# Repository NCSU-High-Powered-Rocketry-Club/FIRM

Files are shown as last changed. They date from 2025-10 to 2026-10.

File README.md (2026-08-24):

# FIRM
Filtered Inertial Rotation Module

FIRM is a project by the NCSU High Powered Rocketry Club to develop a flight computer for high powered rockets. The flight computer is designed to provide accurate attitude and position data during flight using an array of sensors and advanced filtering algorithms.

It is also designed to be modular and easily adaptable to different rocket configurations and mission requirements. The project will also have a custom PCB design to integrate all the components into a compact and lightweight package suitable for high-speed flight.

This repository contains both the embedded code (written in C) that is compiled directly on the STM32 microcontroller, as well as the client code (written in Rust) that will act as the interface between the user-facing API and the hardware.

## Hardware Components

The components used in this project include:

| Part Number | Description | Datasheet Link |
| --- | --- | --- |
| ICM-45686 | 6 Axis IMU | [Datasheet](https://www.mouser.com/catalog/specsheets/TDK_DS_000577_ICM_45686.pdf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) |
| STM32F405RGT6  | Microcontroller | [Datasheet](https://www.st.com/resource/en/datasheet/dm00037051.pdf) |
| MMC5983MA | Magnetometer | [Datasheet](https://media.digikey.com/pdf/Data%20Sheets/MEMSIC%20PDFs/MMC5983MA_RevA_4-3-19.pdf)  |
| BMP581 | Pressure Sensor | [Datasheet](https://www.bosch-sensortec.com/media/boschsensortec/downloads/datasheets/bst-bmp581-ds004.pdf) |

## Project Setup

To set up the project for either embedded development in C or client development in Rust, you will need [uv](https://docs.astral.sh/uv/) installed, and clone the repository:
```bash
git clone https://github.com/NCSU-High-Powered-Rocketry-Club/FIRM.git
```

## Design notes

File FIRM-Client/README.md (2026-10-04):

# FIRM-Client

A modular Rust library for parsing FIRM data packets, with bindings for Python and WebAssembly.

## Project Structure

The project is organized as a Cargo workspace with the following crates:

- **`firm_core`**: The core `no_std` crate containing the raw USB message parser and data structures. This is the foundation for all other crates and can be used in embedded environments.
- **`firm_rust`**: A high-level Rust API that uses `serialport` to read from a serial device and provides a threaded client for receiving packets.
- **`firm_python`**: Python bindings for the Rust client.
- **`firm_typescript`**: WebAssembly bindings and TypeScript code for using the parser in web applications.

## Philosophy

The goal of FIRM-Client is to provide a single, efficient, and correct implementation of the FIRM parser that can be used across different ecosystems (Rust, Python, Web/JS, Embedded).
By centralizing the parsing logic in `firm_core`, we ensure consistency and reduce code duplication.

## Building

### Prerequisites

- Rust (latest stable)
- Python 3.10+ (for Python bindings)
- `maturin` (for building Python wheels)
- `wasm-pack` (for building WASM)
- Node.js/npm (for TypeScript)

### Build Instructions

We assume that you are using a Unix-like environment (Linux or macOS).

Windows users may need to adapt some commands (we will mention where this is the case), or use
WSL (Windows Subsystem for Linux) for best compatibility.

Make sure you have [Cargo](https://rustup.rs) and [uv](https://docs.astral.sh/uv/getting-started/installation/) installed.

You would also need npm if you want to test the web/TypeScript bindings.
Install it and Node.js here: https://nodejs.org/en/download/

1.  **Build all Rust crates:**

    ```bash
    cargo build
    ```

2.  **Build Python bindings:**

    ```bash
    cargo build -p firm_python
    uv sync
    # or to build a wheel
    uv run maturin build --release
    ```

3.  **Build WASM/TypeScript:**

    ```bash
    cargo install wasm-pack
    cd firm_typescript
    npm install
    npm run clean
    npm run build

    # For testing the code with examples/index.html
    npx serve .
    ```

## Running Tests

Ensure that you are in the FIRM-Client folder and run:

```bash
cargo test
```

## Usage

### Rust

Add `firm_rust` to your `Cargo.toml`.

```rust
use firm_rust::FirmClient;
use std::{thread, time::Duration};

fn main() {
    let mut client = FIRMClient::new("/dev/ttyUSB0", 2_000_000, 0.1);
    client.start();

    loop {
        while let Ok(packet) = client.get_packets(Some(Duration::from_millis(100))) {
            println!("{:#?}", packet);
        }
    }
}
```

### Python

You can install the library via pip (once published) or build from source.

```bash
pip install firm-client
```

This library supports Python 3.10 and above, including Python 3.14 free threaded.

```python
from firm_client import FIRMClient
import time

# Using context manager (automatically starts and stops)
with FIRMClient("/dev/ttyUSB0", baud_rate=2_000_000, timeout=0.1) as client:
    client.get_data_packets(block=True)  # Clear initial packets
    client.zero_out_pressure_altitude()
    while True:
        packets = client.get_data_packets()
        for packet in packets:
            print(packet.timestamp_seconds, packet.raw_acceleration_x_gs)
```

### Web (TypeScript)

todo: Add usage example.

### IMU Fixture Calibration

The interactive accelerometer and gyroscope-bias calibration utility uses the Python client and
NumPy. From the `FIRM-Client` directory, run:

```bash
uv run --extra extras python scripts/calibrate_imu.py COM12
```

Replace `COM12` with the device's serial port. The utility checks for identity IMU calibration,
guides the operator through all 26 numbered fixture sides, prints the fitted values, and asks before
writing them to the device. It does not save captured samples or calibration results to disk.

## Publishing

This is mostly for maintainers, but here are the steps to publish each crate to their respective package registries:

### Rust API (crates.io)

todo (idk actually know yet)

### Python Bindings (PyPI)

We need to to first build wheels for each platform, right now the workflow is to do this locally
and then upload to PyPI. At the minimum, we build for Linux x86_64 and aarch64 for python versions
3.10+, including free threaded wheels.

1. Always bump the version in `firm_python/Cargo.toml` before publishing.

2. Build the wheels 
```bash
# If you're on Linux
./compile.sh

# If you're on Windows
.\compile.ps1
```

This will create wheels in the `target/wheels` directory, for Python versions 3.10 to 3.14,
for both x86_64 and aarch64.

3. Make sure you also have a source distribution:

```bash
uv run maturin sdist
```

4. We will use `uv` to publish these wheels to PyPI. Make sure you are part of the HPRC
   organization on PyPI, so you have access to the project and can publish new versions.

```bash
uv publish target/wheels/*
```

This will ask for PyPI credentials, make sure you get the token from the website.

### TypeScript Package (npm)

1. Always bump the version in `firm_typescript/Cargo.toml` and `package.json` before publishing. Make sure they match.

2. Login to npm

`npm login`

3. Publish it

`npm publish`

(Ensure the version in `package.json` is bumped before publishing.)

## License

Licensed under the MIT License. See `LICENSE` file for details.

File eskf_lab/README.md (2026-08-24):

# FIRM ESKF desktop lab

This tool compiles the production STM32 error-state Kalman filter sources as a fast native
desktop executable, aligns manager-built sensor Parquet, replays it through the filter, and writes
compressed Parquet results for analysis and plotting. It does not reimplement the filter math in
Python.

## Quick start

From the repository root:

```powershell
uv sync
uv run firm-log ingest --launch my-launch --recording primary --flight LOG1.FRM --mag-cal LOG2.FRM --hardware new
uv run firm-log build my-launch/primary
uv run firm-eskf list
uv run firm-eskf run my-launch/primary
uv run firm-eskf serve
```

With no dataset names, `prepare` and `run` process every current recording in `flight_data`:

```powershell
uv run firm-eskf run
```

The first run aligns the native-rate Parquet files. Later runs reuse the aligned Parquet and
binary input, so changing ESKF C code normally requires only an incremental native compile and
replay.

For the normal multi-launch workflow, run every dataset once and then use one tabbed dashboard:

```powershell
uv run firm-eskf run
uv run firm-eskf serve
```

## Managed recording format

ESKF discovers only current recordings under the repository's `flight_data` manager. It does not
scan or fall back to `eskf_lab/datasets`; those legacy files are intentionally left in place while
the new archive starts empty. Until a recording has been ingested and built, `list` is empty and
`prepare`, `run`, and no-argument `serve` report that managed data is unavailable.

```text
flight_data/launches/my-launch/recordings/primary/
  recording.yaml
  originals/flight.frm
  originals/magnetometer-calibration.frm
  derived/flight/current.frm
  decoded/barometer.parquet
  decoded/imu.parquet
  decoded/magnetometer.parquet
  decoded/high-g.parquet
```

The manager writes stable corrected column names and keeps raw and uncalibrated fields alongside
them. ESKF retains those extra fields with a sensor prefix so they remain selectable in plots.
Manager outputs are always expressed in the new-hardware sensor frame, including migrated legacy
recordings, so ESKF replay consistently uses the current hardware orientation matrices.

When `rocket_properties.json` is present, it must contain:

```json
{
  "rocket": {
    "rocket_Cd": 0.393,
    "rocket_dry_mass_kg": 16.601,
    "rocket_cross_sectional_area_m2": 0.0182414692475
  }
}
```

The lab then runs HPRM's one-dimensional RK45 apogee predictor from the ESKF altitude and vertical
velocity during the coast-to-apogee portion of the replay. The resulting
`hprm_predicted_apogee_m` column is included in the default dashboard and report plots. Datasets
without the optional file have no HPRM column or graph.

## Commands

```text
firm-eskf list
firm-eskf prepare [DATASET ...] [--force]
firm-eskf run [DATASET ...] [--force-prepare] [--force]
firm-eskf test
firm-eskf inspect RESULT
firm-eskf plot RESULT [--columns COLUMN ...] [--open]
firm-eskf compare RESULT RESULT [--columns COLUMN ...] [--open]
firm-eskf serve [RESULT] [--port 8050]
```

`RESULT` can be a `result.parquet` path, a run directory, or a dataset name. A dataset name selects
its latest run. `inspect` lists every available raw and filter column.

`run --force` bypasses the native ESKF tests and replays the filter even if those tests would fail.
It is intended for deliberately testing broken or experimental filter changes. The older,
equivalent spelling `--skip-native-tests` remains supported. This does not rebuild input caches;
use `--force-prepare` separately when that is required.

`serve` starts a dashboard whose column selector lazily reads only the requested Parquet fields.
With no `RESULT`, it opens every dataset's latest run in a single browser dashboard. Each dataset
has a top-level tab; tabs have a minimum width and wrap to additional rows on smaller screens. Pass
`RESULT` to serve only one dataset instead:

```powershell
uv run firm-eskf serve
uv run firm-eskf serve my-launch
```

`plot` writes a standalone HTML report for one run, while `compare` overlays the same selected
columns across two or more runs. Both use min/max downsampling so short spikes survive while the
browser receives a manageable number of points. When both are selected,
`raw_baro_altitude_m` and `eskf_position_z_m` are intentionally drawn together on the same
**Altitude (m)** chart for direct comparison.

## Replay model

The filter uses IMU, barometer, and magnetometer data. High-g accelerometer values are aligned and
retained for comparisons but are not passed to the current ESKF because
`STM32/Core/Src/tasks/filter_data_task.c` does not use that sensor.

The manager resolves the recording's effective accelerometer, gyroscope, magnetometer, and high-g
calibration before writing Parquet. ESKF consumes those corrected columns directly while retaining
the raw and uncalibrated columns for inspection.

Sensor files have independent timestamps. The magnetometer is the slowest required stream in FIRM
logs, so its samples form the update clock. Each replay row uses the most recent IMU, barometer,
and high-g sample at or before that timestamp, reproducing the firmware's shared-data snapshot
semantics. The first two seconds are accumulated for ESKF initialization.

The native target directly compiles:

- `error_state_kalman_filter.c`
- `eskf_functions.c`
- `eskf_config.c`
- `matrix_helper.c`

A small host shim supplies firmware settings without HAL or FreeRTOS. Results record the filter
source hash, Git revision and dirty state, dataset fingerprint, build path, timing, and descriptive
metrics. Pressure-derived altitude is useful for comparing smoothness but is explicitly not treated
as ground truth.

## Reading results and warnings

Each replay creates a timestamped directory under `eskf_lab/results/<dataset>/` containing:

- `result.parquet`: the aligned raw sensor fields, ESKF state, covariance diagonals, and diagnostics
- `metrics.json`: speed, apogee, smoothness, and finite-state summary
- `run.json`: source/configuration provenance for reproducing the run

`non-finite state values` means at least one ESKF state became `NaN` or `+/-Infinity`. This is a
filter numerical-stability warning, not a CSV parsing warning. Once it happens, later calculations
usually remain invalid. Use the last finite time region in the dashboard, covariance columns, and
the raw sensor traces to diagnose the configuration or model behavior that preceded it.

## Generated files

Generated ESKF artifacts are ignored by Git:

- `eskf_lab/cache`: aligned Parquet and compact replay input
- `eskf_lab/results`: timestamped result Parquet, metadata, metrics, and plots
- `eskf_lab/build`: native CMake build

Delete a recording's cache or use `prepare --force` to rebuild it. The manager build fingerprint
automatically invalidates stale data caches; CMake automatically rebuilds changed filter sources.

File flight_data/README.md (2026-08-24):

# FIRM flight data

This directory is the catalog root for the FIRM flight-data manager.

Each launch can contain several recordings (for example, airbrakes, grave, and zombie). A recording
contains an immutable flight log, an optional immutable magnetometer-calibration log, a manifest,
and rebuildable derived artifacts.

```text
flight_data/launches/<launch>/recordings/<recording>/
  recording.yaml
  originals/flight.frm
  originals/magnetometer-calibration.frm
  overrides/calibration.yaml
  derived/flight/current.frm
  derived/magnetometer-calibration/current.frm
  derived/effective-calibration.yaml
  derived/build.json
  decoded/barometer.parquet
  decoded/imu.parquet
  decoded/magnetometer.parquet
  decoded/high-g.parquet
  decoded/magnetometer-calibration.parquet
```

Start by ingesting a pair of logs, then build their current artifacts:

```powershell
uv run firm-log ingest --launch jackpot-4 --recording airbrakes `
  --flight C:\logs\LOG42.FRM --mag-cal C:\logs\LOG40.FRM --hardware new
uv run firm-log build jackpot-4/airbrakes
uv run firm-eskf list
```

Originals are copied and SHA-256 hashed. Manager commands never modify them. Calibration overrides,
trim windows, migrated logs, and decoded data are all reproducible from `recording.yaml`.

Every recording declares `--hardware old|new` at ingestion. Migration rotates old-hardware IMU
accelerometer and gyroscope bins into the new-hardware sensor frame and transforms their calibration
offsets and matrices with the same change of basis. Barometer and magnetometer data are unchanged;
old recordings may legitimately produce an empty high-g Parquet file. For recordings ingested
before this field existed, use `firm-log hardware set LAUNCH/RECORDING old|new` before building.
Calibration overrides are written in the recording's original sensor frame; the build transforms
old-hardware accel and gyro overrides along with the calibration stored in the original header.

Use `firm-log inspect`, `validate`, and `status` to audit recordings. Calibration changes use
`firm-log calibration set`; explicit or reviewed phase trim windows use `firm-log trim`; `rebuild
--all` refreshes every stale recording. CSV remains an explicit export format rather than an
authoritative artifact.

Git tracks catalog manifests and documentation, but ignores acquired logs, derived logs, Parquet,
and local indexes. A team storage or synchronization system can therefore mirror the complete
`flight_data` tree without putting large binaries in normal Git history; `archive.yaml`,
`launch.yaml`, and `recording.yaml` remain the authoritative, rebuildable catalog.

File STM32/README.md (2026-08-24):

# Embedded FIRM
This contains all of the STM32-based embedded code that runs on FIRM itself.

## Environment Setup

1. Download the STM32CubeCLT from the [STMicroelectronics website](https://www.st.com/en/development-tools/stm32cubeclt.html) and install it on your machine.

2. Install the [STM32 VS Code Extension](https://marketplace.visualstudio.com/items?itemName=stmicroelectronics.stm32-vscode-extension).

3. Restart VS Code.

4. Open the STM32 folder of the repo in VS Code and use the extension to import the folder with the
"Import CMake project" button.

5. Configure your workspace by accepting the default settings from the pop-up messages in VS Code.

6. Click the "Build" button on the bottom status bar to build the project.

7. Run `uv sync`.

8. Run `uv run pre-commit install` to set up the git hook for automatic code formatting and linting, using `clang-format` & `clang-tidy`.

## Building the project

In VS Code, press `Ctrl+Shift+B` to bring up the build menu.
Then click "CMake: build". You should see the build output in the terminal.

## Flashing the firmware

To flash the firmware onto the STM32 microcontroller, follow these steps:

1. Connect the ST-Link Debugger to your computer, and jump the GND, SWDIO, and SWCLK pins from the ST-Link onto FIRM (see the back of the PCB for pin locations).

2. Power FIRM via a USB-C cable or another power source.

3. In VSCode, hit `Ctrl+Shift+P` to open the command palette. Then search for `Run Task` and select it. Then select the option which says to flash via SWD. 

### Running the debugger

Running the debugger is very similar to flashing the firmware.

Make sure you still have the ST-Link hooked onto FIRM, and then go to the Run and Debug tab on the left side of VS Code (or hit `Ctrl+Shift+D`).

Then simply click the green play button at the top of the sidebar to start a debugging session.

## Tracing

Tracing can be used to show how long each thread is running for.

To get a trace, debug the board with a ST-LINK. Pause execution, open up the `Debug Console`, and run

```
>dump binary value trace.bin trace_data
```

The `>` is required for the command to be interpreted as a GDB command. This will save the trace to `STM32/trace.bin`.

To format the trace, run `uv run .\python\scripts\convert_trace.py -i .\STM32\trace.bin -o trace.json` from the root of the repository.

This will produce a json trace that can be visualized in [spall](https://gravitymoth.com/spall/spall.html) or [perfetto](https://ui.perfetto.dev)

## Third party licenses

Contains FATFS changes from https://github.com/MathewMorrow/STM32-SD-Logging-DMA (MIT Licensed)

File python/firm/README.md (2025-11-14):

## FIRM Python Library

This directory contains the Python library for FIRM, which provides tools and utilities for working with the FIRM firmware and hardware components.

## Installation

You can install the FIRM Python library using pip:

```bash
pip install firm-hprc
```

## Usage

After installing the library, you can import it in your Python scripts:

```python
from firm import FIRM

firm = FIRM("/path/to/device")  # e.g. "/dev/ttyUSB0" or "COM3"
firm.initialize()
data = f.get_data_packets()
print(data[0].accel_x_meters_per_s2)
```

The returned data packet is a `FIRMPacket`, which contains various sensor readings and status information. See the source code [here](https://github.com/NCSU-High-Powered-Rocketry-Club/FIRM/blob/main/python/firm/packets.py) on what fields are available.

## Zeroing Out Pressure Altitude

You can zero out the pressure altitude reading to set the current altitude as the new reference (0 meters) using the `zero_out_pressure_altitude` method:

```python
firm.zero_out_pressure_altitude()
packets = firm.get_data_packets()
print(packets[0].pressure_altitude_meters)  # Should be ~0.0 after zeroing out
```

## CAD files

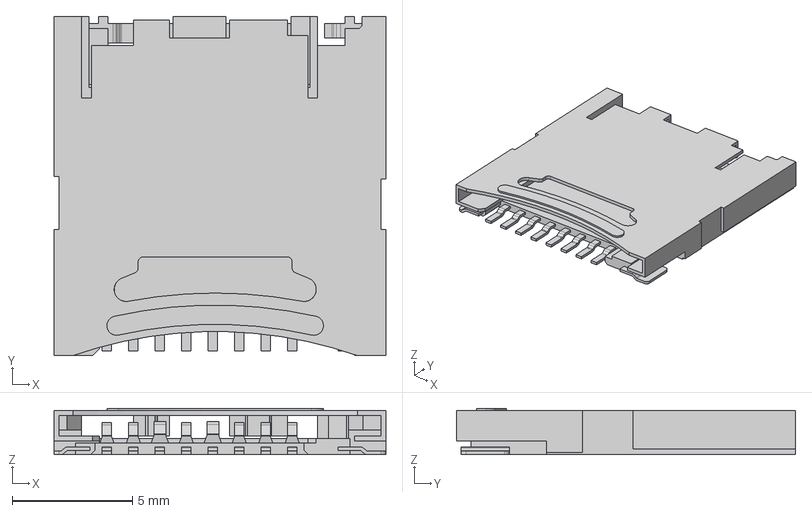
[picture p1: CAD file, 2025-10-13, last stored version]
KiCad/3dmodels/DM3CS-SF.step
13.8 x 14.1 x 1.93 mm

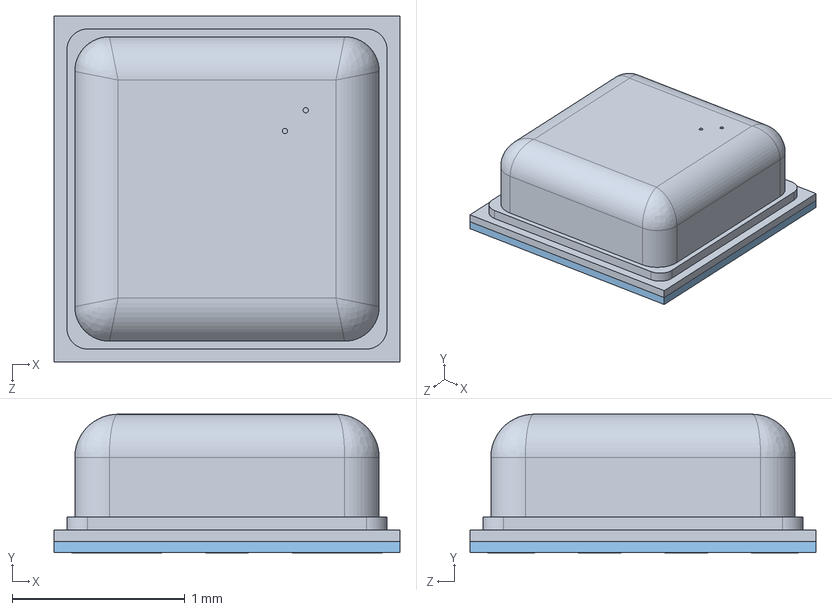
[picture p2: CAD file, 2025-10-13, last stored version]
KiCad/3dmodels/BMP581.step
2.00 x 0.801 x 2.00 mm

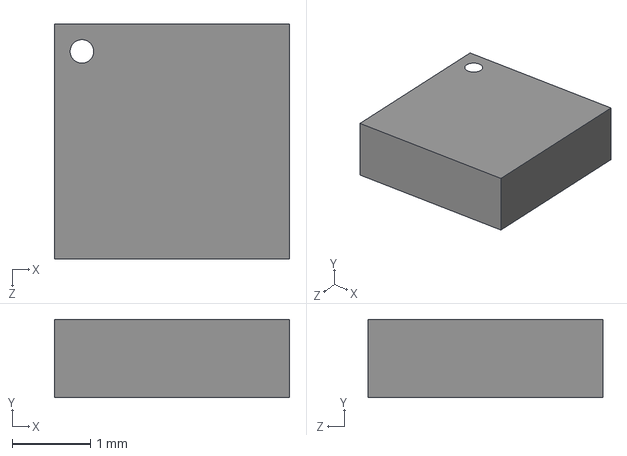
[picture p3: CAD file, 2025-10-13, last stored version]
KiCad/3dmodels/MMC5983MA.step
3.00 x 1.00 x 3.00 mm

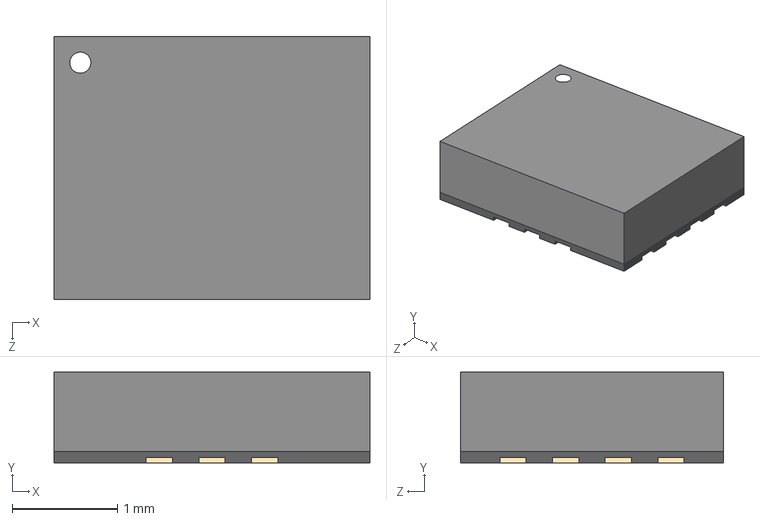
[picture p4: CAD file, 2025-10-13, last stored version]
KiCad/3dmodels/ICM-45686.step
3.00 x 0.86 x 2.50 mm

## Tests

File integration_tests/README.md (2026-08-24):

# Integration Tests

This folder contains pytest-based integration tests for the TypeScript -> FIRM Client -> mocked USB -> STM32 command pipeline.

The first test exercises `getDeviceInfo()` end to end:

1. TypeScript sends the command.
2. The FIRM Client writes the one-byte command ID over a mocked serial link.
3. A Python USB bridge forwards the command into a small host-built STM32 harness.
4. The STM32 `dispatch_command()` path builds the response.
5. The raw ID-plus-payload response returns to the TypeScript client and is asserted in pytest.

Run from the repo root with:

```bash
pytest integration_tests
```

Requirements:

- Python 3.10+
- `pytest`
- Node.js
- A C compiler such as `gcc` or `clang`

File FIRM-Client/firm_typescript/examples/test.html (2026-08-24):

# FIRM Client Test

Connect to Device

Waiting for connection...

Set Name

Get Device Config Get Device Info Get Calibration

Run Mag Calibration Cancel Reboot

Set Mag Calibration

Set IMU Calibration

Stream Mock Log

Config output...

### Latest Packet:

{ No packet data yet }

### Incoming Serial Bytes:

{ No raw bytes yet }

### Outgoing Serial Bytes:

{ No outgoing bytes yet }

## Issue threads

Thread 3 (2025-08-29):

Code formatting

harshil21, 2025-08-29:
It is very essential to format the code, STM32CubeIDE's builtin formatting tool is complete crap. I don't know the C ecosystem very well, but it seems that [`clang-format`](https://clang.llvm.org/docs/ClangFormat.html) is one of the most popular and widely used formatters.

Obviously that IDE doesn't support an extension which would do it for you, so I plan to add a pre-commit hook which will run the formatter.

Graicc, 2025-08-30:
I can vouch for clang-format, it's what we use at work.

Closed 2025-09-10.

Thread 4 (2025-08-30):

Look into using Zephyr RTOS

grsan45, 2025-08-30:
Frankly I hate rewrites as much as the next guy - but using the STM32Cube framework presents a number of issues:
1. **Code Quality & Maintainability** - The code generated is generally unreadable and hard to follow. If we were to hand this project off to someone in 2 years, even if they've done embedded development before... they're gonna have a hard time figuring out whats going on. On top of that, this repository is a mess with all 5000 files that STM32Cube generates which widely go unused & would be better managed locally by a embedded project manager like PlatformIO.
2. **Chip Specific** - If we have to switch away from the STM32F405RGT6 for any reason (supply issues, change in scope, etc). we are basically SOL and sent into a full rewrite anyways. It would be nice to have a more abstracted RTOS that's fairly chip agnostic.
3. **Forced into using terrible development environments** -- we can all agree that the STM32CubeMX IDE sucks. Even with some decent integration with CLion (and maybe vscode thru a plugin), its still a pain to use.

With these issues in mind, I think it may be worth looking into using Zephyr, which is a RTOS for embedded systems. It's more low-level than arduino-based frameworks and has very good custom board support. The code I've seen in samples and documentation is very readable, and it already includes tons of drivers - including ones for the sensors we plan on using.

It would be pretty easy to get going since the Adafruit stm32f405xx feather is an already supported board.

[Zephyr homepage](https://www.zephyrproject.org/)
[Zephyr docs](https://docs.zephyrproject.org/latest)
[Zephyr github](https://github.com/zephyrproject-rtos/zephyr)
[Code sample using a sensor on i2c or spi](https://github.com/zephyrproject-rtos/zephyr/blob/main/samples/sensor/6dof_motion_drdy)

grsan45, 2025-08-30:
After some more reading, I'd be remiss if I didn't also mention FreeRTOS and ThreadX. I've seen some threads suggesting using those over Zephyr. The main complaints I've seen on Zephyr are regarding its configuration complexity (though it seems those are all from several years ago when documentation appears to have been non-existent), so if that proves to be an issue then the aforementioned alternatives could be the move. From what I've seen, ThreadX may be a little bit much for our project, its designed for much higher-performance & multi-threaded applications. FreeRTOS is incredibly simple but doesn't have the driver support like Zephyr does. If we don't mind writing some of these drivers ourselves (which we might have to anyways) it might be the better option.

wlsanderson, 2025-08-30:
So I did a lot of research on Zephyr and RTOS's in general, and personally I am of the opinion that Zephyr isn't a good fit for this project. I do think a scheduler would be very important for FIRM, so I think FreeRTOS is a good suggestion that would definitely help to futureproof our code once we increase the scope of the project. I'm definitely open to more discussion on this though.

Firstly, I definitely agree that CubeIDE is not great. And while implementing an RTOS (PlatformIO or Zephyr specifically) would allow us to move to CLion or VS Code, we can also move to these IDE's without using an RTOS (and we planned to do this soon). So I don't really think that the IDE choice is a great argument for using an RTOS. Our plan was to configure pinouts, peripherals, clock timings, etc., for the STM32, and then once the foundational hardware/firmware was set up, then we move to our preferred IDE. CubeIDE is not pretty, but CubeMX's GUI and code generation is extremely useful and easy to use, and from what I read online, it's extremely difficult and much less user-friendly to do the same configuration in another software/IDE. Also, PlatformIO is definitely out of the picture, just because there's a lot of people that say that setting up custom boards is an awful experience.

As for the chip compatibility and portability, from what I understand, it's going to be shitty no matter what. Especially once we are dealing with a custom board (not the Adafruit Feather), we won't have an easy import and will have to reconfigure a lot of settings in Zephyr. The biggest issue with chip portability is that pinouts will most likely change, so not only will the code change but we would have to get a whole new PCB design as well. CubeMX also makes it easier than Zephyr to set up pinouts and change hardware-based configs. Zephyr is definitely better if we ended up switching to a chip that is non-STM32, but that just seems like a bad idea in the first place.

The most convincing argument for Zephyr is definitely the file structure. I agree that CubeMX gives us a ton of HAL files and bloats up the repo, and Zephyr makes this easier to manage with Kconfig and the device tree. The best we could do with CubeMX is manually prune and .gitignore unneeded/unchanging files, but it's time consuming and prone to issues.

In the end, I don't really think Zephyr is worth it, especially because of the steeper learning curve that I've seen a lot of people mention. In the future if we give our project to new people, they might struggle to understand the STM32Cube file structure, but the alternative is struggling with the learning curve of Zephyr. I think FreeRTOS is a good middle ground that adds the benefits of an RTOS but doesn't complicate other things or slow down the current workflow.

Aman-Anas, 2025-08-30:
Looks like PlatformIO supports Zephyr and FreeRTOS

wlsanderson, 2025-08-30:
Many people suggest not to use platformIO with stm32 custom boards. Its a hassle to set up properly apparently, and its just another abstraction layer that isn't needed. PlatformIO seems like it was designed with Arduino and ESP32 boards in mind, not custom boards. I'm sure its possible to use it, but I think it would be just extra bloat and make it harder to get to the lower level configs when we need to.

Aman-Anas, 2025-08-31:
Never used FreeRTOS before but it seems like stm32 should be officially supported. They have some demo projects [**here**](https://www.freertos.org/Documentation/02-Kernel/03-Supported-devices/04-Demos/02-Supported-demos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)

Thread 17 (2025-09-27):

Restructure the Repository

wlsanderson, 2025-09-27:
Our repository is just the STM32 code right now, but FIRM has multiple other important files that need to be version controlled, namely the KiCad project, and the python files (magnetometer calibration script, and decoder). In the future we would also have another folder for launch data logs.

This is probably a good start for what the repo structure should be:

FIRM
├─ KiCad/
├─ STM32/
└─ scripts/

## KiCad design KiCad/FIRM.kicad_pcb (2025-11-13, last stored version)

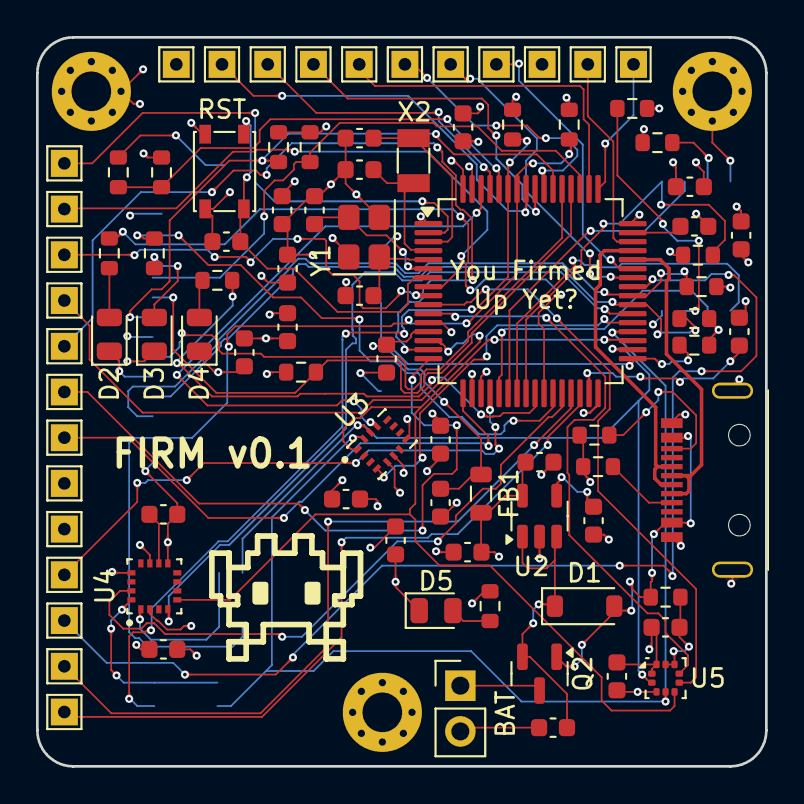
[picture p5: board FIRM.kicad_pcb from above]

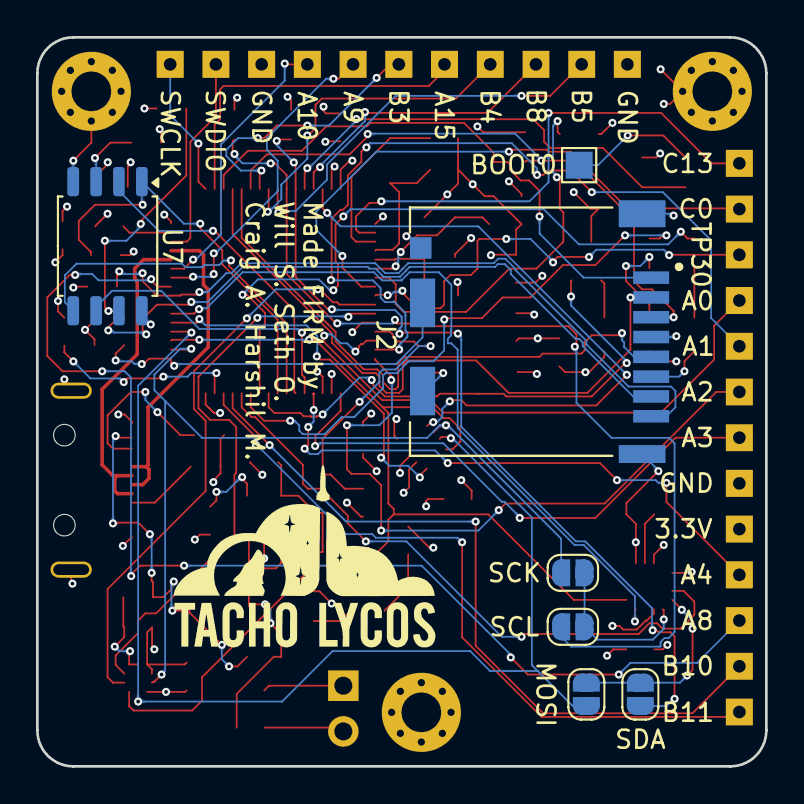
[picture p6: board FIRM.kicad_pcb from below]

Board: 4 copper layers, 40.5 x 40.5 mm, 98 parts (7 on the bottom side), 74 nets.

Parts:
3.3V: 3.3V Test Point; TestPoint_THTPad_1.5x1.5mm_Drill0.7mm
A0: PA0 Test Point; TestPoint_THTPad_1.5x1.5mm_Drill0.7mm
A1: PA1 Test Point; TestPoint_THTPad_1.5x1.5mm_Drill0.7mm
A2: PA2 Test Point; TestPoint_THTPad_1.5x1.5mm_Drill0.7mm
A3: PA3 Test Point; TestPoint_THTPad_1.5x1.5mm_Drill0.7mm
A4: PA4 Test Point; TestPoint_THTPad_1.5x1.5mm_Drill0.7mm
A8: PA8 Test Point; TestPoint_THTPad_1.5x1.5mm_Drill0.7mm
A9: PA9 Test Point; TestPoint_THTPad_1.5x1.5mm_Drill0.7mm
A10: PA10 Test Point; TestPoint_THTPad_1.5x1.5mm_Drill0.7mm
A15: PA15 Test Point; TestPoint_THTPad_1.5x1.5mm_Drill0.7mm
B3: PB3 Test Point; TestPoint_THTPad_1.5x1.5mm_Drill0.7mm
B4: PB4 Test Point; TestPoint_THTPad_1.5x1.5mm_Drill0.7mm
B5: PB5 Test Point; TestPoint_THTPad_1.5x1.5mm_Drill0.7mm
B8: PB8 Test Point; TestPoint_THTPad_1.5x1.5mm_Drill0.7mm
B10: PB10 Test Point; TestPoint_THTPad_1.5x1.5mm_Drill0.7mm
B11: PB11 Test Point; TestPoint_THTPad_1.5x1.5mm_Drill0.7mm
BAT: Conn_01x02_Pin; PinHeader_1x02_P2.54mm_Vertical
BOOT0: BOOT0 Pad; TestPoint_Pad_1.5x1.5mm
C0: PC0 Test Point; TestPoint_THTPad_1.5x1.5mm_Drill0.7mm
C1, C2, C3, C4, C5, C19, C20, C21, C25, C26, C27: 100n; C_0603_1608Metric
C6: 4u7; C_0603_1608Metric
C7: 10n; C_0603_1608Metric
C8, C15: 0.1u; C_0603_1608Metric
C9, C10: 2u2; C_0603_1608Metric
C11, C12: 6p; C_0603_1608Metric
C13: PC13 Test Point; TestPoint_THTPad_1.5x1.5mm_Drill0.7mm
C13#2, C14: 14p; C_0603_1608Metric
C16, C18: 1u; C_0603_1608Metric
C17, C22, C24: 10u; C_0603_1608Metric
C23: 470p; C_0603_1608Metric
D1: D_Schottky; D_SOD-123
D2, D3, D4, D5: LED; LED_0805_2012Metric
FB1: 120 Ohms @ 100 MHz; L_0805_2012Metric
GND: GND Test Point; TestPoint_THTPad_1.5x1.5mm_Drill0.7mm
GND#2: GND Through-Hole; TestPoint_THTPad_1.5x1.5mm_Drill0.7mm
GND#3: GND Test Point; TestPoint_THTPad_1.5x1.5mm_Drill0.7mm
H1, H2, H3: MountingHole_Pad; MountingHole_2.2mm_M2_Pad_Via
J2: DM3CS-SF; HRS_DM3CS-SF
MOSI: SPI_SDI; SolderJumper-2_P1.3mm_Open_RoundedPad1.0x1.5mm
Q2: IRLML6402; SOT-23
R1, R8: 100k; R_0603_1608Metric
R2, R3, R4, R5, R6: 47k; R_0603_1608Metric
R7, R13, R14, R21: 10k; R_0603_1608Metric
R9, R22: 5.1k; R_0603_1608Metric
R10: 330; R_0603_1608Metric
R11, R15: 1k2; R_0603_1608Metric
R12: 1k5; R_0603_1608Metric
R18, R19: 2k2; R_0603_1608Metric
R20: 100; R_0603_1608Metric
RST: PTS815; SW_SPST_PTS810
SCK: SPI_SCK; SolderJumper-2_P1.3mm_Open_RoundedPad1.0x1.5mm
SCL: I2C_SCL; SolderJumper-2_P1.3mm_Open_RoundedPad1.0x1.5mm
SDA: I2C_SDA; SolderJumper-2_P1.3mm_Open_RoundedPad1.0x1.5mm
SWCLK: SWCLK Through-Hole; TestPoint_THTPad_1.5x1.5mm_Drill0.7mm
SWDIO: SWDIO Through-Hole; TestPoint_THTPad_1.5x1.5mm_Drill0.7mm
TP30: PC1 Test Point; TestPoint_THTPad_1.5x1.5mm_Drill0.7mm
U1: STM32F405RGTx; LQFP-64_10x10mm_P0.5mm
U2: MIC5219-3.3YM5; SOT-23-5
U3: IC_ICM-45686
U4: IC_MMC5983MA
U5: ST_HLGA-10_2x2mm_P0.5mm_LayoutBorder3x2y
U6: A-USBC-20F0-EA-GSR05
U7: W25Q128JVS; SOIC-8_5.3x5.3mm_P1.27mm
X2: 32.768khz; Crystal_SMD_3215-2Pin_3.2x1.5mm
Y1: 12 MHz; Crystal_SMD_Abracon_ABM8G-4Pin_3.2x2.5mm

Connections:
+3.3V: 3.3V.1, C1.1, C2.1, C3.1, C4.1, C5.1, C6.1, C16.1, C18.1, C19.1, C20.1, C21.2, C24.1, C25.1, C26.2, C27.2, FB1.2, J2.4 (VDD), R2.2, R3.2, R4.2, R5.2, R6.2, R7.1, R13.1, R14.1, R15.2, R18.2, R19.2, R21.1, U1.1 (VBAT), U1.19 (VDD), U1.32 (VDD), U1.48 (VDD), U1.64 (VDD), U2.5 (OUT), U3.5 (VDDIO), U3.8 (VDD), U4.2 (VDD), U4.13 (VDDIO), U5.1 (VDDIO), U5.10 (VDD), U7.8 (VCC)
/BMP_CS: U1.10 (PC2), U5.6 (CSB)
/BMP_INT: U1.11 (PC3), U5.7 (INT)
/BOOT0: R1.1, R20.2, U1.60 (BOOT0)
/DBUG_0: R10.2, U1.26 (PB0)
/DBUG_1: R11.2, U1.27 (PB1)
/DBUG_2: R12.2, U1.25 (PC5)
/FLASH_CS: R21.2, U1.24 (PC4), U7.1 (~CS)
/HSE_IN: C13#2.1, U1.5 (PH0), Y1.1
/HSE_OUT: C14.1, U1.6 (PH1), Y1.3
/I2C1_SCL: R18.1, SCL.2 (B), U1.58 (PB6)
/I2C1_SDA: R19.1, SDA.2 (B), U1.59 (PB7)
/IMU_CS: U1.62 (PB9), U3.12 (AP_CS)
/IMU_INT: U1.37 (PC6), U3.4 (INT1/INT)
/LSE_IN: C11.1, U1.3 (PC14), X2.1
/LSE_OUT: C12.1, U1.4 (PC15), X2.2
/MAG_CS: U1.38 (PC7), U4.4 (SPI_CS)
/MAG_INT: U1.28 (PB2), U4.15 (INT)
/MISO1: U1.22 (PA6), U7.2 (DO/IO_{1})
/MISO2: U1.35 (PB14), U3.1 (AP_SDO/AP_AD0), U4.5 (SPI_SDO), U5.5 (SDO)
/MOSI1: U1.23 (PA7), U7.5 (DI/IO_{0})
/MOSI2: MOSI.2 (B), U1.36 (PB15), U3.14 (AP_SDA/APSDIO/APSDI), U5.4 (SDI)
/NRST: C15.1, RST.1, U1.7 (NRST)
/PA0: A0.1, U1.14 (PA0)
/PA1: A1.1, U1.15 (PA1)
/PA2: A2.1, U1.16 (PA2)
/PA3: A3.1, U1.17 (PA3)
/PA4: A4.1, U1.20 (PA4)
/PA8: A8.1, U1.41 (PA8)
/PA9: A9.1, U1.42 (PA9)
/PA10: A10.1, U1.43 (PA10)
/PA15: A15.1, U1.50 (PA15)
/PB3: B3.1, U1.55 (PB3)
/PB4: B4.1, U1.56 (PB4)
/PB5: B5.1, U1.57 (PB5)
/PB8: B8.1, U1.61 (PB8)
/PB10: B10.1, U1.29 (PB10)
/PB11: B11.1, U1.30 (PB11)
/PC0: C0.1, U1.8 (PC0)
/PC1: TP30.1, U1.9 (PC1)
/PC13: C13.1, U1.2 (PC13)
/SCK1: U1.21 (PA5), U7.6 (CLK)
/SCK2: SCK.2 (B), U1.34 (PB13), U3.13 (AP_SCL/AP_SCLK), U5.2 (SCK)
/SDIO_CK: J2.5 (CLK), U1.53 (PC12)
/SDIO_CMD: J2.3 (CMD), R4.1, U1.54 (PD2)
/SDIO_D0: J2.7 (DAT0), R5.1, U1.39 (PC8)
/SDIO_D1: J2.8 (DAT1), R6.1, U1.40 (PC9)
/SDIO_D2: J2.1 (DAT2), R2.1, U1.51 (PC10)
/SDIO_D3: J2.2 (CD/DAT3), R3.1, U1.52 (PC11)
/SD_DETECT: J2.9 (CD_SW), R7.2, U1.33 (PB12)
/SWCLK: SWCLK.1, U1.49 (PA14)
/SWDIO: SWDIO.1, U1.46 (PA13)
/USB_D+: U1.45 (PA12), U6.A6 (D+), U6.B6 (D+)
/USB_D-: U1.44 (PA11), U6.A7 (D-), U6.B7 (D-)
/VCAP1: C9.1, U1.31 (VCAP_1)
/VCAP2: C10.1, U1.47 (VCAP_2)
GND: BAT.2, C1.2, C2.2, C3.2, C4.2, C5.2, C6.2, C7.2, C8.2, C9.2, C10.2, C11.2, C12.2, C13#2.2, C14.2, C15.2, C16.2, C17.1, C18.2, C19.2, C20.2, C21.1, C22.2, C23.2, C24.2, C25.2, C26.1, C27.1, D2.1 (K), D3.1 (K), D4.1 (K), D5.1 (K), GND.1, GND#2.1, GND#3.1, H1.1, H2.1, H3.1, J2.6 (VSS), J2.S1 (GND), J2.S2 (GND), J2.S3 (GND), J2.S5 (GND), R1.2, R8.2, R9.2, R22.2, RST.2, U1.12 (VSSA), U1.18 (VSS), U1.63 (VSS), U2.2 (GND), U3.6 (GND), U4.9 (GND), U4.11 (GND), U5.3 (VSS), U5.8 (VSS), U5.9 (VSS), U6.A1 (GND), U6.B1 (GND), U6.S1 (SHIELD), U7.4 (GND), Y1.2, Y1.4
unnamed: C22.1, D1.1 (K), Q2.2 (S), U2.1 (IN), U2.3 (EN)
unnamed: D2.2 (A), R10.1
unnamed: D3.2 (A), R11.1
unnamed: D4.2 (A), R12.1
unnamed: D5.2 (A), R15.1
unnamed: MOSI.1 (A), SDA.1 (A), U4.16 (SDA/ SPI_SDI)
unnamed: SCK.1 (A), SCL.1 (A), U4.1 (SCL/ SPI_SCK)
unnamed: BOOT0.1, R20.1
unnamed: C7.1, C8.1, FB1.1, U1.13 (VDDA)
unnamed: C23.1, U2.4 (BP)
unnamed: C17.2, U4.10 (CAP)
unnamed: R9.1, U6.A5 (CC1)
unnamed: R22.1, U6.B5 (CC2)
unnamed: R13.2, U7.7 (~HOLD/~RESET/IO_{3})
unnamed: R14.2, U7.3 (~WP/IO_{2})
VBAT: BAT.1, Q2.3 (D)
VBUS: D1.2 (A), Q2.1 (G), R8.1, U6.A4 (VBUS), U6.B4 (VBUS)

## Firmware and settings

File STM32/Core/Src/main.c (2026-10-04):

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
/* Includes ------------------------------------------------------------------*/
#include "main.h"
#include "cmsis_os.h"
#include "fatfs.h"
#include "usb_device.h"

/* USER CODE BEGIN Includes */
#include "mode_indicator_task.h"
#include "sensor_task.h"
#include "filter_data_task.h"
#include "packetizer_task.h"
#include "transmit_task.h"
#include "usb_read_data_task.h"
#include "transmit_frame.h"
#include "led.h"
#include "logger.h"
#include "mocking_handler.h"
#include "packets.h"
#include "sensor_manager.h"
#include "settings_manager.h"
#include "system_settings.h"
#include "system_state.h"
#include "targets.h"
#include "firm_v1_0.h"

#include "FreeRTOS.h"
#include "event_groups.h"
#include "queue.h"
#include "semphr.h"
#include "stream_buffer.h"
#include "task.h"

#include <bmp581.h>
#include <icm45686.h>
#include <mmc5983ma.h>
#include <adxl371.h>

#include <stdbool.h>
#include <stddef.h>
#include <stdio.h>
#include <string.h>


/* USER CODE END Includes */

/* USER CODE BEGIN PD */

#define MOCK_QUEUE_LENGTH 50U

/* USER CODE END PD */

I2C_HandleTypeDef hi2c1;
I2C_HandleTypeDef hi2c2;

SD_HandleTypeDef hsd;
DMA_HandleTypeDef hdma_sdio_rx;
DMA_HandleTypeDef hdma_sdio_tx;

SPI_HandleTypeDef hspi1;
SPI_HandleTypeDef hspi2;
SPI_HandleTypeDef hspi3;

UART_HandleTypeDef huart1;
DMA_HandleTypeDef hdma_usart1_tx;

/* Definitions for defaultTask */
osThreadId_t defaultTaskHandle;
const osThreadAttr_t defaultTask_attributes = {
  .name = "defaultTask",
  .stack_size = 256 * 4,
  .priority = (osPriority_t) osPriorityRealtime1,
};
/* Definitions for startupTask */
osThreadId_t startupTaskHandle;
const osThreadAttr_t startupTask_attributes = {
  .name = "startupTask",
  .stack_size = 256 * 4,
  .priority = (osPriority_t) osPriorityRealtime,
};
/* USER CODE BEGIN PV */

static DataPacket_t global_data_packet = {0};
static Calibration_t startup_calibration_buffer;

/* USER CODE END PV */

void SystemClock_Config(void);
static void MX_GPIO_Init(void);
static void MX_DMA_Init(void);
static void MX_I2C1_Init(void);
static void MX_I2C2_Init(void);
static void MX_SDIO_SD_Init(void);
static void MX_SPI2_Init(void);
static void MX_SPI3_Init(void);
static void MX_SPI1_Init(void);
static void MX_USART1_UART_Init(void);
void StartDefaultTask(void *argument);
void StartupTask(void *argument);

/* USER CODE BEGIN PFP */

static bool mock_count_try_take(void *context);
static bool mock_count_give(void *context);
static size_t mock_count_get_count(void *context);
static void mock_count_reset(void *context);
static void firm_rtos_init(void);
static void configure_mocking_injection(void);
static uint32_t firm_time_cyccnt(void);
static void apply_stored_sensor_calibrations(void);

/* USER CODE END PFP */

/* USER CODE BEGIN 0 */

static bool mock_count_try_take(void *context) {
  return xSemaphoreTake((SemaphoreHandle_t)context, 0U) == pdTRUE;
}

static bool mock_count_give(void *context) {
  return xSemaphoreGive((SemaphoreHandle_t)context) == pdTRUE;
}

static size_t mock_count_get_count(void *context) {
  return (size_t)uxSemaphoreGetCount((SemaphoreHandle_t)context);
}

static void mock_count_reset(void *context) {
  while (xSemaphoreTake((SemaphoreHandle_t)context, 0U) == pdTRUE) {
  }
}

static uint32_t firm_time_cyccnt(void) {
  return DWT->CYCCNT;
}

static void apply_stored_sensor_calibrations(void) {
  const uint8_t *settings_bytes = (const uint8_t *)get_settings();

  // SystemSettings_t is packed. Copy one calibration at a time into aligned static storage before
  // passing it to a driver. Keeping this buffer out of StartupTask's stack is important: that task
  // has a 1 KiB stack and runs several deeply nested hardware initialization routines.
  memcpy(&startup_calibration_buffer, settings_bytes + offsetof(SystemSettings_t, accel_cal),
         sizeof(startup_calibration_buffer));
  icm45686_set_accel_calibration(startup_calibration_buffer.offset,
                                 startup_calibration_buffer.scale_matrix);

  memcpy(&startup_calibration_buffer, settings_bytes + offsetof(SystemSettings_t, gyro_cal),
         sizeof(startup_calibration_buffer));
  icm45686_set_gyro_calibration(startup_calibration_buffer.offset,
                                startup_calibration_buffer.scale_matrix);

  memcpy(&startup_calibration_buffer, settings_bytes + offsetof(SystemSettings_t, mag_cal),
         sizeof(startup_calibration_buffer));
  mmc5983ma_set_calibration(startup_calibration_buffer.offset,
                            startup_calibration_buffer.scale_matrix);

  memcpy(&startup_calibration_buffer, settings_bytes + offsetof(SystemSettings_t, high_g_cal),
         sizeof(startup_calibration_buffer));
  adxl371_set_calibration(startup_calibration_buffer.offset,
                          startup_calibration_buffer.scale_matrix);
}

static void configure_mocking_injection(void) {
  MockSensorTaskInjectFns_t inject_fns = {
      .set_time_fn = set_time_fn,
      .set_barometer_read_fn = set_barometer_read_fn,
      .set_imu_read_fn = set_imu_read_fn,
      .set_magnetometer_read_fn = set_magnetometer_read_fn,
      .set_high_g_read_fn = set_high_g_read_fn,
      .get_time_fn = sensor_manager_get_time_fn,
      .get_barometer_read_fn = sensor_manager_get_barometer_read_fn,
      .get_imu_read_fn = sensor_manager_get_imu_read_fn,
      .get_magnetometer_read_fn = sensor_manager_get_magnetometer_read_fn,
      .get_high_g_read_fn = sensor_manager_get_high_g_read_fn,
  };

  mocking_handler_configure_sensor_task_injection(&inject_fns);
}

static void firm_rtos_init(void) {
  usb_rx_stream =
      xStreamBufferCreate(USB_RX_STREAM_BUFFER_SIZE_BYTES, USB_RX_STREAM_TRIGGER_LEVEL_BYTES);
  transmit_queue = xQueueCreate(TRANSMIT_QUEUE_LENGTH, sizeof(TransmitFrame_t));
  sensor_event_group = xEventGroupCreate();
  sensor_collected_group = xEventGroupCreate();

  if (usb_rx_stream == NULL || transmit_queue == NULL || sensor_event_group == NULL ||
      sensor_collected_group == NULL) {
    Error_Handler();
  }

  SemaphoreHandle_t mock_count_sem = xSemaphoreCreateCounting(MOCK_QUEUE_LENGTH, 0U);
  if (mock_count_sem != NULL) {
    MockRingCountSemaphore_t mock_counting_semaphore = {
        .context = mock_count_sem,
        .try_take = mock_count_try_take,
        .give = mock_count_give,
        .get_count = mock_count_get_count,
        .reset = mock_count_reset,
    };

    uint32_t hclk_hz = HAL_RCC_GetHCLKFreq();
    uint32_t hclk_mhz = (hclk_hz == 0U) ? 168U : (hclk_hz / 1000000U);
    mocking_handler_init(&mock_counting_semaphore, hclk_mhz);
  }

  configure_mocking_injection();
}

/* USER CODE END 0 */

/**
  * @brief  The application entry point.
  * @retval int
  */
int main(void)
{

  /* MCU Configuration--------------------------------------------------------*/

  /* Reset of all peripherals, Initializes the Flash interface and the Systick. */
  HAL_Init();

  /* Configure the system clock */
  SystemClock_Config();

  /* Initialize all configured peripherals */
  MX_GPIO_Init();
  MX_DMA_Init();
  MX_I2C1_Init();
  MX_I2C2_Init();
  MX_SDIO_SD_Init();
  MX_SPI2_Init();
  MX_SPI3_Init();
  MX_SPI1_Init();
  MX_USART1_UART_Init();
  MX_FATFS_Init();
  /* USER CODE BEGIN 2 */

  if (firm_init_hardware())
    Error_Handler();

  /* USER CODE END 2 */

  /* Init scheduler */
  osKernelInitialize();

  /* USER CODE BEGIN RTOS_SEMAPHORES */
  /* add semaphores, ... */
  /* USER CODE END RTOS_SEMAPHORES */

  /* USER CODE BEGIN RTOS_TIMERS */
  /* start timers, add new ones, ... */
  /* USER CODE END RTOS_TIMERS */

  /* USER CODE BEGIN RTOS_QUEUES */
  firm_rtos_init();
  /* USER CODE END RTOS_QUEUES */

  /* Create the thread(s) */
  /* creation of defaultTask */
  defaultTaskHandle = osThreadNew(StartDefaultTask, NULL, &defaultTask_attributes);

  /* creation of startupTask */
  startupTaskHandle = osThreadNew(StartupTask, NULL, &startupTask_attributes);

  /* USER CODE BEGIN RTOS_THREADS */
  firm_mode_indicator_task_handle =
      osThreadNew(firm_mode_indicator_task, NULL, &modeIndicatorTask_attributes);
  sensor_task_handle = osThreadNew(sensor_task, &global_data_packet, &sensorTask_attributes);
  packetizer_task_handle = osThreadNew(packetizer_task, &global_data_packet, &packetizerTask_attributes);
  filter_data_task_handle = osThreadNew(filter_data_task, &global_data_packet, &filterDataTask_attributes);
  transmit_task_handle = osThreadNew(transmit_data, NULL, &transmitTask_attributes);
  usb_read_task_handle = osThreadNew(usb_read_data, NULL, &usbReadTask_attributes);

  if (firm_mode_indicator_task_handle == NULL || sensor_task_handle == NULL ||
      filter_data_task_handle == NULL || packetizer_task_handle == NULL ||
      transmit_task_handle == NULL || usb_read_task_handle == NULL) {
    Error_Handler();
  }
  /* USER CODE END RTOS_THREADS */

  /* USER CODE BEGIN RTOS_EVENTS */
  /* add events, ... */
  /* USER CODE END RTOS_EVENTS */

  /* Start scheduler */
  osKernelStart();

  /* We should never get here as control is now taken by the scheduler */

  /* Infinite loop */
  /* USER CODE BEGIN WHILE */
  Error_Handler();
  while (1) {
    /* USER CODE END WHILE */

    /* USER CODE BEGIN 3 */
  }
  /* USER CODE END 3 */
}

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
/* USER CODE BEGIN 4 */

/**
 * @brief ISR for interrupt pins
 * @note all ISR signals use this function, must check which pin before setting data ready flags
 * @param GPIO_Pin the EXTI pin that triggered the interrupt signal
 * @retval None
 */
void HAL_GPIO_EXTI_Callback(uint16_t GPIO_Pin) {
  BaseType_t xHigherPriorityTaskWoken = pdFALSE;

  if (sensor_event_group == NULL) {
    return;
  }

  if (GPIO_Pin == BMP581_Interrupt_Pin) {
    (void)xEventGroupSetBitsFromISR(sensor_event_group, SENSOR_EVENT_BAROMETER_READY,
                                    &xHigherPriorityTaskWoken);
  }
  if (GPIO_Pin == ICM45686_Interrupt_Pin) {
    (void)xEventGroupSetBitsFromISR(sensor_event_group, SENSOR_EVENT_IMU_READY,
                                    &xHigherPriorityTaskWoken);
  }
  if (GPIO_Pin == MMC5983MA_Interrupt_Pin) {
    (void)xEventGroupSetBitsFromISR(sensor_event_group, SENSOR_EVENT_MAGNETOMETER_READY,
                                    &xHigherPriorityTaskWoken);
  }
  if (GPIO_Pin == ADXL371_Interrupt_Pin) {
    (void)xEventGroupSetBitsFromISR(sensor_event_group, SENSOR_EVENT_HIGH_G_READY,
                                    &xHigherPriorityTaskWoken);
  }
  portYIELD_FROM_ISR(xHigherPriorityTaskWoken);
}
/* USER CODE END 4 */

/* USER CODE BEGIN Header_StartDefaultTask */
/**
 * @brief  Function implementing the defaultTask thread.
 * @param  argument: Not used
 * @retval None
 */
/* USER CODE END Header_StartDefaultTask */
void StartDefaultTask(void *argument)
{
  /* init code for USB_DEVICE */
  MX_USB_DEVICE_Init();
  /* USER CODE BEGIN 5 */
  /* Infinite loop */
  vTaskDelete(NULL);
  /* USER CODE END 5 */
}

/* USER CODE BEGIN Header_StartupTask */
/**
 * @brief Function implementing the startupTask thread.
 * @param argument: Not used
 * @retval None
 */
/* USER CODE END Header_StartupTask */
void StartupTask(void *argument)
{
  /* USER CODE BEGIN StartupTask */

  system_state_set(SYSTEM_STATE_BOOT);

  // We use DWT (Data Watchpoint and Trace unit) to get a high resolution free-running timer.
  CoreDebug->DEMCR |= CoreDebug_DEMCR_TRCENA_Msk;
  DWT->CYCCNT = 0;
  DWT->CTRL |= DWT_CTRL_CYCCNTENA_Msk;

  set_time_fn(firm_time_cyccnt);

  // Ensure SPI chip-select lines default to not selected.
  HAL_GPIO_WritePin(GPIOC, GPIO_PIN_2, GPIO_PIN_SET); // BMP581 CS pin
  HAL_GPIO_WritePin(GPIOB, GPIO_PIN_9, GPIO_PIN_SET); // ICM45686 CS pin
  HAL_GPIO_WritePin(GPIOC, GPIO_PIN_4, GPIO_PIN_SET); // flash chip CS pin
  HAL_GPIO_WritePin(GPIOC, GPIO_PIN_7, GPIO_PIN_SET); // MMC5983MA CS pin
  HAL_GPIO_WritePin(GPIOA, GPIO_PIN_8, GPIO_PIN_SET); // ADXL371 CS pin

  HAL_Delay(100);

  // The scheduler is not running yet; prevent EXTI callbacks from notifying task handles.
  HAL_NVIC_DisableIRQ(EXTI0_IRQn);
  HAL_NVIC_DisableIRQ(EXTI1_IRQn);
  HAL_NVIC_DisableIRQ(EXTI2_IRQn);
  HAL_NVIC_DisableIRQ(EXTI3_IRQn);

  if (icm45686_init()) {
    led_set_status(IMU_FAIL);
    Error_Handler();
  }

  if (mmc5983ma_init()) {
    led_set_status(MMC5983MA_FAIL);
    Error_Handler();
  }

  if (bmp581_init()) {
    led_set_status(BMP581_FAIL);
    Error_Handler();
  }

  if (adxl371_init()) {
    led_set_status(HIGH_G_FAIL);
    Error_Handler();
  }
  
  // set up the settings manager
  if (settings_manager_init()) {
    led_set_status(FLASH_CHIP_FAIL);
    Error_Handler();
  }

  // Sensor drivers keep their active calibration in RAM, so load the values restored from flash.
  apply_stored_sensor_calibrations();

  // setup logger with the sensor data sizes
  logger_set_sensor_info(sizeof(BMP581RawData_t), sizeof(ICM45686RawData_t),
                         sizeof(MMC5983MARawData_t), sizeof(ADXL371RawData_t));

  // Open a new log and emit the metadata header.
  if (create_log()) {
    Error_Handler();
  }
  if (logger_write_header(*get_settings())) {
    Error_Handler();
  }

  // re-enable ISR's so that interrupts can trigger the sensor tasks to run
  HAL_NVIC_EnableIRQ(EXTI0_IRQn);
  HAL_NVIC_EnableIRQ(EXTI1_IRQn);
  HAL_NVIC_EnableIRQ(EXTI2_IRQn);
  HAL_NVIC_EnableIRQ(EXTI3_IRQn);

  vTaskDelete(NULL);
  /* USER CODE END StartupTask */
}

/**
  * @brief  Period elapsed callback in non blocking mode
  * @note   This function is called  when TIM2 interrupt took place, inside
  * HAL_TIM_IRQHandler(). It makes a direct call to HAL_IncTick() to increment
  * a global variable "uwTick" used as application time base.
  * @param  htim : TIM handle
  * @retval None
  */
void HAL_TIM_PeriodElapsedCallback(TIM_HandleTypeDef *htim)
{
  if (htim->Instance == TIM2)
  {
    HAL_IncTick();
  }
}

/**
  * @brief  This function is executed in case of error occurrence.
  * @retval None
  */
void Error_Handler(void)
{
  /* USER CODE BEGIN Error_Handler_Debug */
  /* User can add his own implementation to report the HAL error return state */
  __disable_irq();
  while (1) {
  }
  /* USER CODE END Error_Handler_Debug */
}
#ifdef USE_FULL_ASSERT
/**
  * @brief  Reports the name of the source file and the source line number
  *         where the assert_param error has occurred.
  * @param  file: pointer to the source file name
  * @param  line: assert_param error line source number
  * @retval None
  */
void assert_failed(uint8_t *file, uint32_t line)
{
  /* USER CODE BEGIN 6 */
  /* User can add his own implementation to report the file name and line number,
     ex: printf("Wrong parameters value: file %s on line %d\r\n", file, line) */
  /* USER CODE END 6 */
}
#endif /* USE_FULL_ASSERT */

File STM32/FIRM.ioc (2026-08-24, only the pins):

Mcu.UserName=STM32F405RGTx
PA10.Signal=USART1_RX
PA11.Signal=USB_OTG_FS_DM
PA12.Signal=USB_OTG_FS_DP
PA13.Signal=SYS_JTMS-SWDIO
PA14.Signal=SYS_JTCK-SWCLK
PA4.GPIO_Label=CONF_CHECK
PA4.Signal=GPIO_Input
PA5.Signal=SPI1_SCK
PA6.Signal=SPI1_MISO
PA7.Signal=SPI1_MOSI
PA8.GPIO_Label=ADXL371_CS
PA8.Signal=GPIO_Output
PA9.Signal=USART1_TX
PB0.GPIO_Label=ICM45686_Interrupt
PB0.Signal=GPXTI0
PB1.GPIO_Label=ADXL371_Interrupt
PB1.Signal=GPXTI1
PB10.Signal=I2C2_SCL
PB11.Signal=I2C2_SDA
PB12.Signal=GPIO_Input
PB13.Signal=SPI2_SCK
PB14.Signal=SPI2_MISO
PB15.Signal=SPI2_MOSI
PB2.GPIO_Label=MMC5983MA_Interrupt
PB2.Signal=GPXTI2
PB3.Signal=SPI3_SCK
PB4.Signal=SPI3_MISO
PB5.Signal=SPI3_MOSI
PB6.Signal=I2C1_SCL
PB7.Signal=I2C1_SDA
PB8.GPIO_Label=DEBUG1
PB8.Signal=GPIO_Output
PB9.GPIO_Label=ICM45686_CS
PB9.Signal=GPIO_Output
PC0.Signal=GPIO_Output
PC1.GPIO_Label=DEBUG0
PC1.Signal=GPIO_Output
PC10.Signal=SDIO_D2
PC11.Signal=SDIO_D3
PC12.Signal=SDIO_CK
PC2.GPIO_Label=BMP581_CS
PC2.Signal=GPIO_Output
PC3.GPIO_Label=BMP581_Interrupt
PC3.Signal=GPXTI3
PC4.GPIO_Label=FLASH_CS
PC4.Signal=GPIO_Output
PC5.GPIO_Label=DEBUG2
PC5.Signal=GPIO_Output
PC7.GPIO_Label=MMC5983MA_CS
PC7.Signal=GPIO_Output
PC8.Signal=SDIO_D0
PC9.Signal=SDIO_D1
PD2.Signal=SDIO_CMD
PH0-OSC_IN.Signal=RCC_OSC_IN
PH1-OSC_OUT.Signal=RCC_OSC_OUT

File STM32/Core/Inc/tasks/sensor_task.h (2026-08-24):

#pragma once

#include "sensor_manager.h"
#include "packets.h"
#include "shared_data/identifiers.h"

#include "cmsis_os.h"
#include "event_groups.h"

#define BMP581_POLL_RATE_HZ 255
#define ICM45686_POLL_RATE_HZ 400
#define MMC5983MA_POLL_RATE_HZ 225
#define ADXL371_POLL_RATE_HZ 160

// Event bits for data-ready interrupts.
#define SENSOR_EVENT_BAROMETER_READY (1U << 0)
#define SENSOR_EVENT_IMU_READY (1U << 1)
#define SENSOR_EVENT_MAGNETOMETER_READY (1U << 2)
#define SENSOR_EVENT_HIGH_G_READY (1U << 3)

// Event bits for sensor data collected.
#define SENSOR_COLLECTED_BAROMETER_BIT (1U << 0)
#define SENSOR_COLLECTED_IMU_BIT (1U << 1)
#define SENSOR_COLLECTED_MAGNETOMETER_BIT (1U << 2)
#define SENSOR_COLLECTED_HIGH_G_BIT (1U << 3)

extern osThreadId_t sensor_task_handle;
extern const osThreadAttr_t sensorTask_attributes;

extern EventGroupHandle_t sensor_event_group;
extern EventGroupHandle_t sensor_collected_group;

void sensor_task(void *argument);

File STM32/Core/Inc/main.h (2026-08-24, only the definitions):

#define DEBUG0_Pin GPIO_PIN_1
#define DEBUG0_GPIO_Port GPIOC
#define BMP581_CS_Pin GPIO_PIN_2
#define BMP581_CS_GPIO_Port GPIOC
#define BMP581_Interrupt_Pin GPIO_PIN_3
#define BMP581_Interrupt_GPIO_Port GPIOC
#define BMP581_Interrupt_EXTI_IRQn EXTI3_IRQn
#define CONF_CHECK_Pin GPIO_PIN_4
#define CONF_CHECK_GPIO_Port GPIOA
#define FLASH_CS_Pin GPIO_PIN_4
#define FLASH_CS_GPIO_Port GPIOC
#define DEBUG2_Pin GPIO_PIN_5
#define DEBUG2_GPIO_Port GPIOC
#define ICM45686_Interrupt_Pin GPIO_PIN_0
#define ICM45686_Interrupt_GPIO_Port GPIOB
#define ICM45686_Interrupt_EXTI_IRQn EXTI0_IRQn
#define ADXL371_Interrupt_Pin GPIO_PIN_1
#define ADXL371_Interrupt_GPIO_Port GPIOB
#define ADXL371_Interrupt_EXTI_IRQn EXTI1_IRQn
#define MMC5983MA_Interrupt_Pin GPIO_PIN_2
#define MMC5983MA_Interrupt_GPIO_Port GPIOB
#define MMC5983MA_Interrupt_EXTI_IRQn EXTI2_IRQn
#define MMC5983MA_CS_Pin GPIO_PIN_7
#define MMC5983MA_CS_GPIO_Port GPIOC
#define ADXL371_CS_Pin GPIO_PIN_8
#define ADXL371_CS_GPIO_Port GPIOA
#define DEBUG1_Pin GPIO_PIN_8
#define DEBUG1_GPIO_Port GPIOB
#define ICM45686_CS_Pin GPIO_PIN_9
#define ICM45686_CS_GPIO_Port GPIOB
#define FIRM_HARDWARE_VERSION VERSION_V1_0

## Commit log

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2025-08-30 Add comments to imu code, some formatting, slightly increase correctness
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2025-09-10 [pre-commit.ci] auto fixes from pre-commit.com hooks
    for more information, see https://pre-commit.ci
    [main.c]
2025-09-16 Revert moving the cs line high to init
    [main.c]
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2025-09-17 imu fix
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2025-09-22 testing set and reset
    [FIRM.ioc, main.c, main.h]
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2025-10-01 kicad files
    [FIRM.kicad_pcb, FIRM.kicad_sch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]
2025-10-01 fixed stm32 code
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2025-10-03 update with drive
    [FIRM.kicad_sch]
2025-10-03 connector jst
    [FIRM.kicad_sch]
2025-10-03 Sensors Power/Decoupling and IMU/MMC Footprints
    Fixed ICM, BMP, and MMC's power and decoupling. Added footprints for the MMC and ICM
    [FIRM.kicad_sch]
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2025-10-03 Solder jump pads for the magnetometer
    [FIRM.kicad_sch]
2025-10-03 USB-C pullup resistors and no-connects
    [FIRM.kicad_sch]
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2025-10-07 add crystal parts
    [FIRM.kicad_sch]
2025-10-07 LEDs, reset button, i2c pullups
    [FIRM.kicad_sch]
2025-10-07 breakout unused pins
    [FIRM.kicad_sch]
2025-10-07 boot0 pin
    [FIRM.kicad_sch]
2025-10-07 fix warnings
    [FIRM.kicad_sch]
2025-10-10 voltage regulator
    [FIRM.kicad_sch]
2025-10-10 update datasheets
    [FIRM.kicad_sch]
2025-10-10 i forgot to save
    [FIRM.kicad_sch]
2025-10-10 footprints and start pcb
    [FIRM.kicad_pcb, FIRM.kicad_sch]
2025-10-10 changing some sizes
    [FIRM.kicad_pcb, FIRM.kicad_sch]
2025-10-11 update crystal and sd card port
    [DM3CS-SF.step, FIRM.kicad_pcb, FIRM.kicad_sch]
2025-10-11 rough layout
    [FIRM.kicad_pcb]
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2025-10-12 Use project library instead of global library
    Also reorganize footprints, custom symbols, and 3d models. Updated README about using KiCad in the project.
    [BMP581.step, DM3CS-SF.step, FIRM.kicad_pcb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]
2025-10-12 Use the correct ICM-45686 symbol in sensors/
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2025-10-13 Created Footprint and Symbol for the USBC we picked out.
    I had to make the footprint and symbol because they weren't available online. Look over the shield pads and the diameter of the 2 circles (diameter is 1.2mm but it looks smaller on the datasheet)
    [FIRM.kicad_sch]
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2025-10-14 Add LCSC part numbers
    [FIRM.kicad_sch]
2025-10-14 im firm
    [FIRM.kicad_pcb, FIRM.kicad_sch]
2025-10-14 log and decode clock cycles, prevent overflow
    [main.c]
2025-10-14 fixed imu cal
2025-10-15 for the clanker
    [FIRM.kicad_pcb, FIRM.kicad_sch]
2025-10-15 Finish part numbers
    [FIRM.kicad_sch]
2025-10-15 bom digikey
    [FIRM.kicad_pcb, FIRM.kicad_sch]
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2025-10-15 update bom
    [FIRM.kicad_sch]
2025-10-16 almost done?
    [FIRM.kicad_pcb]
2025-10-16 almost done
    [FIRM.kicad_pcb]
2025-10-17 chat we are so back
    [FIRM.kicad_pcb]
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2025-10-17 fix fb and cap
    [FIRM.kicad_pcb, FIRM.kicad_sch]
2025-10-17 refine traces
    [FIRM.kicad_pcb]
2025-10-17 Add silkscreen art, update MMC footprint solder mask expansion
    [FIRM.kicad_pcb]
2025-10-18 Update via size
    [FIRM.kicad_pcb]
2025-10-18 fixed some traces
    [FIRM.kicad_pcb]
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2025-10-25 well theres your issue, you're dereferencing a null pointer!
    [main.c]
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2025-10-28 Some fixes to the one shot mode and __init__
    [firm.py]
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2025-10-29 Pick and place fixes
    [FIRM.kicad_pcb, FIRM.kicad_sch]
2025-10-30 fix magnetometer flip
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2025-11-08 panic if freertos start fails, cmake changes & openocd
    [stm32f4x.cfg]
2025-11-08 revert old dma changes in diskio as they are no longer needed, openocd update
    [stm32f4x.cfg]
2025-11-13 Update .gitignore for Kicad file types
    Added various Kicad temporary and backup file patterns to .gitignore.
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2025-11-27 Map to a correct pin state
2025-11-28 Blink LEDs for failed interrupt triggers
2025-11-28 Migrate KiCad files to other repo
    Also update README
    [BMP581.step, DM3CS-SF.step, FIRM.kicad_pcb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]
2025-12-01 [pre-commit.ci] pre-commit autoupdate
    - [github.com/pre-commit/mirrors-clang-format: v21.1.2 → v21.1.6](https://github.com/pre-commit/mirrors-clang-format/compare/v21.1.2...v21.1.6)
    - [github.com/astral-sh/ruff-pre-commit: v0.14.3 → v0.14.7](https://github.com/astral-sh/ruff-pre-commit/compare/v0.14.3...v0.14.7)
    - [github.com/cpp-linter/cpp-linter-hooks: v1.1.9 → v1.1.10](https://github.com/cpp-linter/cpp-linter-hooks/compare/v1.1.9...v1.1.10)
    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
2025-12-20 mostly works, missing interrupt led status
    [main.c]
2025-12-25 Added reboot and calibration commands
2026-01-05 [pre-commit.ci] pre-commit autoupdate
    - [github.com/pre-commit/mirrors-clang-format: v21.1.6 → v21.1.8](https://github.com/pre-commit/mirrors-clang-format/compare/v21.1.6...v21.1.8)
    - [github.com/astral-sh/ruff-pre-commit: v0.14.7 → v0.14.10](https://github.com/astral-sh/ruff-pre-commit/compare/v0.14.7...v0.14.10)
    - [github.com/cpp-linter/cpp-linter-hooks: v1.1.10 → v1.1.11](https://github.com/cpp-linter/cpp-linter-hooks/compare/v1.1.10...v1.1.11)
    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
2026-01-27 fixed imu breaking
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2026-02-11 Fixed calibration code and added GetCalibration command
2026-02-20 Fix magnet buildup in MMC
2026-03-02 fixed boards
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2026-03-17 fix board orientation comments
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2026-03-23 fix adxl scale factor in header
    [main.c]
2026-03-25 sensor orientation in mocks fix
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2026-04-10 hopefully deleted and moved files correctly
    [stm32f4x.cfg]
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2026-04-19 some fixes, and test setup
    [main.c]
2026-04-27 bunch of slop code
    [main.c, sensor_task.h]
2026-04-28 slop code the integration
    [main.c, sensor_task.h]
2026-08-12 fixed everything i think
    [client_packets.rs, firm_packets.rs, main.c]
2026-08-24 log manager
    [calibration.yaml]
2026-09-23 imu cal script and bug fixes in firmware
    [main.c]
2026-09-24 chore: match clang-format pre-commit to STM32/Core
    The old ^Core/ regex never matched after firmware moved under STM32/.
    Point clang-tidy at the root firmware-debug compile database.
2026-09-25 refactor: move FIRM-Client to client and hoist the Cargo workspace
    Keep the crates under client/ so the STM32 tree stays the firmware
    root, and build them from the repository Cargo.toml.
2026-09-25 refactor: move post-flight tools into processing/
    Keep firm.flight_data for log archives, merge the ESKF Python package
    with native C under processing/eskf_lab, and turn leftover scripts into
    firm-trace and firm-reconstruct entry modules.
2026-09-25 build: add root CMake presets for firmware and host
    Firmware presets still add_subdirectory(STM32) with the ARM toolchain.
    The host preset builds ESKF CTest, the C header layout check, and an
    optional Ceedling wrapper.
2026-09-25 build: add just recipes for build, test, lint, and ci
    Local just test runs every suite and prints a pass/fail summary so CI
    jobs can call the same recipes in parallel.
2026-09-25 docs: document the unified layout and commands
    Point contributors at just, the root CMake presets, firm-trace, and
    firm_client instead of the old scripts and CRC Python client.
2026-09-25 Fix rust example and don't use "type" to reexport DeviceProtocol
2026-09-25 Fix firm-trace task labels and the capture-plot ruff failure.
2026-10-03 Drop Python 3.10 support; require 3.11+
    Bump requires-python and ruff's target to 3.11, drop 3.10 from classifiers,
    wheel build scripts and docs, and adopt tomllib/datetime.UTC/typing.Self.
    Also document installing just and trim the README build section.
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2026-11-03 Call sensor drivers directly from sensor_manager.
    Read callbacks existed only so mock mode could swap them. Keep the time-source hook used by live sampling.
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2026-11-03 Check every sensor record ID is rejected as a command
    The deleted mock dispatch test covered 'I', 'M', and 'A'; the replacement
    invalid-command list only kept 'B'.
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2026-11-03 Bring up sensors before any FreeRTOS call and mount the SD card from a task.
    f_mount creates its FatFS sync object with osSemaphoreNew. Before the scheduler starts,
    that critical section leaves BASEPRI raised (uxCriticalNesting begins at 0xaaaaaaaa),
    masking the TIM2 HAL tick, so the HAL_Delay in firm_board_init never returned and the
    board hung at boot.
    firm_init_hardware now deselects the SPI chips and brings up the sensors before any RTOS
    call. The new firm_init_log_storage mounts the SD card and sets up logger storage from
    StartDefaultTask once the kernel is running. sd_diskio skips its own BSP_SD_Init because
    fatfs_sd_init already runs it.
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2026-11-13 Publish the ESKF state estimate in the data packet.
    The est_* fields were left zero while the filter ran. A static assert ties their layout to the ESKF nominal state so the memcpy can't drift out of sync.
2026-11-13 Load new calibration into the sensor drivers when it is set
    ID_SET_MAG_CALIBRATON and ID_SET_IMU_CALIBRATON only wrote flash, and the
    drivers read calibration once at boot. Live data kept the old calibration
    until a reboot, so a client that reset calibration to identity before
    collecting still fitted already-corrected samples and stored a wrong fit.
    commands.c now calls a registered callback after a successful calibration
    write, and main.c uses it to reload all driver calibrations inside a
    critical section.
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2026-11-13 Fence same-kind retries instead of guessing with a grace window
    Replies carry no command id, and the device can drop one when USB stays
    busy. The grace window started when a command timed out, so after a lost
    reply an immediate retry's valid reply landed inside the window and was
    discarded as late. That retry then timed out and opened a new window, so
    every prompt retry failed until the caller paused for longer than the grace.
    Each command waiting for a reply is now tracked in send order with a local
    id, and a call only takes the reply matched to its id. A reply goes to the
    oldest waiting command of its kind; commands sent before that one can no
    longer be answered and are dropped. When a co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
2026-11-13 Respond to the Python set_device_config test only after the command is sent
    The test injected the reply before the command, so it raced the client
    (about 2 runs in 10 failed) and now always fails, since a reply that arrives
    before any command is sent is no longer taken as an answer. It now replies
    from a thread once the command arrives, which needs MockDeviceHandle to be
    sendable; it only wraps Arc<Mutex<..>> state.
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

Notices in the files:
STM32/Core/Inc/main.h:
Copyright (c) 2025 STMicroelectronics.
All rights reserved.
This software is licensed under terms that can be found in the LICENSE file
